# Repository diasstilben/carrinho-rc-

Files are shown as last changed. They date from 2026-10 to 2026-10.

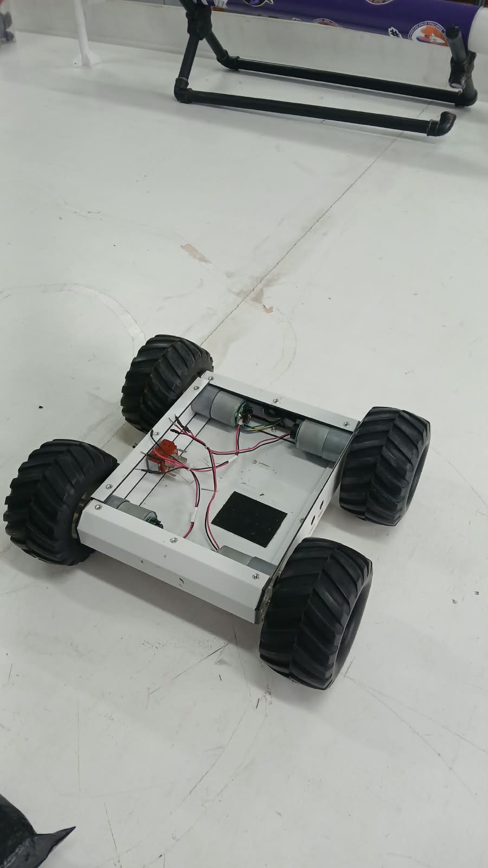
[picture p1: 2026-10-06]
hardware/fotos/carcaça do astro com motores.jpeg

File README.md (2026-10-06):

# 🤖 Carrinho RC com ESP32

Repositório dedicado ao desenvolvimento do hardware, esquemas elétricos e código de controle de um robô móvel de 4 rodas (4WD) baseado em **ESP32 DevKit V1**, controlado por duas pontes H **L298N** e equipado com sensor ultrassônico e alerta sonoro.

---

## 🛠️ Componentes Utilizados

* **Microcontrolador:** ESP32 DevKit V1 (30 pinos)
* **Tração:** 4x Motores DC com caixa de redução (4WD)
* **Acionamento de Motores:** 2x Pontes H L298N (divididas por lado: Esquerdo e Direito)
* **Alimentação:** 4x Baterias de Lítio (configuradas em pack **2S2P** ~7.4V)
* **Navegação/Sensores:** 1x Sensor Ultrassônico HC-SR04
* **Atuador Sonoro:** 1x Buzzer Ativo/Passivo
* **Outros:** Resistores (1kΩ e 2kΩ) para o divisor de tensão, protoboard e jumpers.

---

## ⚡ Esquema de Conexão (Pinout)

### 1. Alimentação e Terra (GND Comum)
* **Bateria (+):** Conectada aos bornes **12V** das duas pontes H (L298N 1 e L298N 2).
* **Bateria (-):** Conectada aos bornes **GND** das pontes H (fechando a malha de terra comum).
* **Alimentação do ESP32:** Puxada do borne **5V** da Ponte H 1 para o pino **VIN** (ou 5V) do ESP32.
* **Alimentação do Sensor:** Puxada do borne **5V** da Ponte H 1 para o pino **VCC** do HC-SR04.

### 2. Sinais de Controle - Motores (ESP32)
> *Nota: Os jumpers de ENA/ENB das pontes H foram removidos para permitir o controle de velocidade via PWM.*

| Pino do ESP32 | Função na Ponte H 1 (Lado Esquerdo) |
| :---: | :--- |
| **GPIO 13** | ENA (Velocidade Motor Esquerdo A) |
| **GPIO 14** | IN1 (Direção Motor Esquerdo A) |
| **GPIO 27** | IN2 (Direção Motor Esquerdo A) |
| **GPIO 26** | IN3 (Direção Motor Esquerdo B) |
| **GPIO 25** | IN4 (Direção Motor Esquerdo B) |
| **GPIO 33** | ENB (Velocidade Motor Esquerdo B) |

| Pino do ESP32 | Função na Ponte H 2 (Lado Direito) |
| :---: | :--- |
| **GPIO 32** | ENA (Velocidade Motor Direito A) |
| **GPIO 22** | IN1 (Direção Motor Direito A) |
| **GPIO 19** | IN2 (Direção Motor Direito A) |
| **GPIO 18** | IN3 (Direção Motor Direito B) |
| **GPIO 16** | IN4 (Direção Motor Direito B) |
| **GPIO 17** | ENB (Velocidade Motor Direito B) |

### 3. Periféricos (Sensor e Buzzer)
| Componente / Pino | Conexão no ESP32 | Observação |
| :--- | :--- | :--- |
| **HC-SR04 (Trig)** | GPIO **4** | Direto |
| **HC-SR04 (Echo)** | GPIO **35** | Protegido por Divisor de Tensão (1kΩ + 2kΩ para o GND) |
| **Buzzer (+)** | GPIO **23** | Sinal de acionamento |

---

## 📁 Estrutura do Repositório

```text
carrinho-rc/
├── README.md                           # Documentação geral do projeto
├── hardware/
│   ├── cad/
│   │   └── CONEXÃO DO CARRINHO RC.fzz  # Esquema elétrico e de montagem (Fritzing)
│   └── fotos/
│       └── carcaça do astro com motores.jpeg # Registros físicos da montagem
└── software/
    ├── software.ino                    # Código principal em C++ 
    └── data/                           # Pasta obrigatória para o LittleFS
        ├── index.html                  # Estrutura do painel de controle
        ├── style.css                   # Estilização visual
        └── script.js                   # Lógica de controle, leitura do teclado e requisições HTTP

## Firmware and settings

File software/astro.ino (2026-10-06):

#include <WiFi.h>
#include <WebServer.h>
#include <LittleFS.h>

// ==========================================
// 1. CONFIGURAÇÃO DA REDE WI-FI (Access Point)
// ==========================================
const char* ssid = "Astro_Rc";
const char* password = "dias";

// Inicia o servidor web na porta padrão HTTP (80)
WebServer server(80);

// ==========================================
// 2. CONFIGURAÇÃO DOS PINOS E MOTORES
// ==========================================
// Motores Lado Esquerdo
const int ENA_ESQ = 13;
const int IN1_ESQ = 14;
const int IN2_ESQ = 27;
const int IN3_ESQ = 26;
const int IN4_ESQ = 25;
const int ENB_ESQ = 33;

// Motores Lado Direito
const int ENA_DIR = 32;
const int IN1_DIR = 22;
const int IN2_DIR = 19;
const int IN3_DIR = 18;
const int IN4_DIR = 16;
const int ENB_DIR = 17;

// Pino da Buzina
const int BUZINA_PIN = 23;

// Pinos do Sensor
const int TRIG_PIN = 4;
const int ECHO_PIN = 35; 
// Variáveis para o controle do sensor de ré 
bool emRe = false;
bool buzinaReAtiva = false;
unsigned long ultimoTempoBip = 0;
int estadoBuzinaRe = LOW;

// Declaração antecipada da função parar para o configurarPinos não dar erro
void parar(); 

void configurarPinos() {
    // Configura os pinos de direção como SAÍDA
    pinMode(IN1_ESQ, OUTPUT); pinMode(IN2_ESQ, OUTPUT);
    pinMode(IN3_ESQ, OUTPUT); pinMode(IN4_ESQ, OUTPUT);
    pinMode(IN1_DIR, OUTPUT); pinMode(IN2_DIR, OUTPUT);
    pinMode(IN3_DIR, OUTPUT); pinMode(IN4_DIR, OUTPUT);
    
    // Configura buzina e garante que comece desligada
    pinMode(BUZINA_PIN, OUTPUT);
    digitalWrite(BUZINA_PIN, LOW);

    // Configura os pinos do Sensor Ultrassônico (CORRIGIDO: Faltava configurar)
    pinMode(TRIG_PIN, OUTPUT);
    pinMode(ECHO_PIN, INPUT);

    // Configura o PWM para o controle de velocidade (1000 Hz, 10 bits = 0 a 1023)
    ledcAttach(ENA_ESQ, 1000, 10);
    ledcAttach(ENB_ESQ, 1000, 10);
    ledcAttach(ENA_DIR, 1000, 10);
    ledcAttach(ENB_DIR, 1000, 10);
    
    parar(); // Garante que o robô inicie parado
}

// Função base para acionar as pontes H
void moverMotores(int v1_esq, int v2_esq, int v3_esq, int v4_esq, 
                  int v1_dir, int v2_dir, int v3_dir, int v4_dir, int val_pwm) {
    digitalWrite(IN1_ESQ, v1_esq); digitalWrite(IN2_ESQ, v2_esq);
    digitalWrite(IN3_ESQ, v3_esq); digitalWrite(IN4_ESQ, v4_esq);
    
    digitalWrite(IN1_DIR, v1_dir); digitalWrite(IN2_DIR, v2_dir);
    digitalWrite(IN3_DIR, v3_dir); digitalWrite(IN4_DIR, v4_dir);

    // Aplica a velocidade (PWM)
    ledcWrite(ENA_ESQ, val_pwm); ledcWrite(ENB_ESQ, val_pwm);
    ledcWrite(ENA_DIR, val_pwm); ledcWrite(ENB_DIR, val_pwm);
}

// Comandos de Movimento
void parar()    { moverMotores(0,0,0,0, 0,0,0,0, 0); }
void frente()   { moverMotores(1,0,1,0, 1,0,1,0, 1023); }
void tras()     { moverMotores(0,1,0,1, 0,1,0,1, 1023); }
void esquerda() { moverMotores(0,1,0,1, 1,0,1,0, 1023); } 
void direita()  { moverMotores(1,0,1,0, 0,1,0,1, 1023); }

// ==========================================
// 3. SERVIDOR DE ARQUIVOS (LittleFS)
// ==========================================
void enviarArquivo(String caminho, String tipoConteudo) {
    if (LittleFS.exists(caminho)) {
        File arquivo = LittleFS.open(caminho, "r");
        server.streamFile(arquivo, tipoConteudo);
        arquivo.close();
    } else {
        server.send(404, "text/plain", "Erro 404: Arquivo nao encontrado no ESP32");
    }
}

long medirDistancia() {
    digitalWrite(TRIG_PIN, LOW);
    delayMicroseconds(2);
    digitalWrite(TRIG_PIN, HIGH);
    delayMicroseconds(10);
    digitalWrite(TRIG_PIN, LOW);

    // Timeout de 30ms (~5 metros no máximo) para não travar o código
    long duracao = pulseIn(ECHO_PIN, HIGH, 30000); 
    
    if (duracao == 0) return 999; // Se não ler nada, assume que tá livre
    return (duracao / 2) / 29.1;  // Converte o tempo do eco para centímetros
}

void desativarAlarmeRe() {
    emRe = false;
    if (buzinaReAtiva) { // Desliga a buzina de ré só se ela estiver apitando
        digitalWrite(BUZINA_PIN, LOW);
        buzinaReAtiva = false;
    }
}

// ==========================================
// 4. SETUP INICIAL DO SISTEMA
// ==========================================
void setup() {
    Serial.begin(115200);
    configurarPinos();

    // Inicia a memória Flash (LittleFS)
    if (!LittleFS.begin(true)) {
        Serial.println("Erro ao montar o LittleFS. Verifique se fez o upload da pasta 'data'.");
        return;
    }
    Serial.println("LittleFS montado com sucesso!");

    // Cria a Rede Wi-Fi
    Serial.println("Iniciando Wi-Fi do Astro...");
    WiFi.softAP(ssid, password);
    Serial.print("Rede criada! IP de acesso: ");
    Serial.println(WiFi.softAPIP()); // O IP será 192.168.4.1

    // ------------------------------------------
    // ROTAS DO SERVIDOR WEB
    // ------------------------------------------
    
    // Entrega o HTML, CSS e JS quando o navegador pedir
    server.on("/", HTTP_GET, []() { enviarArquivo("/index.html", "text/html"); });
    server.on("/index.html", HTTP_GET, []() { enviarArquivo("/index.html", "text/html"); });
    server.on("/style.css", HTTP_GET, []() { enviarArquivo("/style.css", "text/css"); });
    server.on("/script.js", HTTP_GET, []() { enviarArquivo("/script.js", "application/javascript"); });

    // Rotas de Comandos Motores e Buzina 
    server.on("/B", []() { emRe = true; tras(); server.send(200); }); // Ativa a ré
    server.on("/F", []() { desativarAlarmeRe(); frente(); server.send(200); });
    server.on("/L", []() { desativarAlarmeRe(); esquerda(); server.send(200); });
    server.on("/R", []() { desativarAlarmeRe(); direita(); server.send(200); });
    server.on("/S", []() { desativarAlarmeRe(); parar(); server.send(200); });
    server.on("/H", []() { digitalWrite(BUZINA_PIN, HIGH); server.send(200); });
    server.on("/Q", []() { digitalWrite(BUZINA_PIN, LOW); server.send(200); });
    server.on("/ping", []() { server.send(200); });
    
    // Inicia o servidor
    server.begin();
    Serial.println("Servidor pronto! Astro aguardando ordens.");
}

// ==========================================
// 5. LOOP PRINCIPAL
// ==========================================
void loop() { 
    server.handleClient(); // Continua ouvindo o navegador rapidamente

    // Lógica do Sensor de Ré
    if (emRe) {
        long distancia = medirDistancia();
        int intervaloBip = 0;

        if (distancia < 15) {
            intervaloBip = 100; // Menos de 15cm: Bipe muito rápido (cuidado!)
        } else if (distancia < 30) {
            intervaloBip = 300; // Menos de 30cm: Bipe médio
        } else if (distancia < 60) {
            intervaloBip = 600; // Menos de 60cm: Bipe lento
        } else {
            intervaloBip = 0;   // Mais de 60cm: Muito longe, não apita
            if (buzinaReAtiva) {
                digitalWrite(BUZINA_PIN, LOW);
                buzinaReAtiva = false;
            }
        }

        // Toca o bipe no ritmo certo sem usar delay()
        if (intervaloBip > 0) {
            buzinaReAtiva = true;
            if (millis() - ultimoTempoBip >= intervaloBip) {
                ultimoTempoBip = millis(); // Reseta o cronômetro
                estadoBuzinaRe = (estadoBuzinaRe == LOW) ? HIGH : LOW; // Inverte o estado
                digitalWrite(BUZINA_PIN, estadoBuzinaRe);
            }
        }
    }
}

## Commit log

2026-10-03 readme e cad
    [CONEXÃO DO CARRINHO RC.fzz]
2026-10-04 inclui funcoes de ir para tras e ir para frente
    [CONEXÃO DO CARRINHO RC.fzz]
2026-10-04 interface para controle do carrinho
2026-10-05 cortei o fio hahahahahhahaha
    [CONEXÃO DO CARRINHO RC.fzz]
2026-10-06 tive que mudar o codico para C++ :(
2026-10-26 Refiz o modelo cad e adicionei uma foto para quem não tem o fritzing
2026-10-29 adiciona legenda de comandos
2026-10-29 tirei o little fs e troquei a senha do wifi do esp tudo funcionando por enquanto...
